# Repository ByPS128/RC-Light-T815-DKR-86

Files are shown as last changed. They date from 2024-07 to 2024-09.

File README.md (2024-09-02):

# RC-Light Controller for T815-DKR-86

## Introduction

RC-Light Controller is a sophisticated system for controlling the lighting of RC models, specifically designed for the 1:12 scale Tatra 815 1986 DAKAR model. This project combines hardware and software solutions to create a realistic and fully functional lighting system for RC models.

## Prerequisites
The control system assumes the use of an RC pistol transmitter with a steering wheel and at least 3 channels.
1. Channel for steering
2. Channel for throttle/brake
3. Channel of button type or a lever with two states (e.g., start/stop, on/off)

For development purposes, I used an inexpensive RC transmitter: TURBO 2.4GHz 91803G-VT 3CH RC Transmitter.

## Outline

1. [Feature Overview](#feature-overview)
2. [System Architecture](#system-architecture)
3. [Main Components](#main-components)
4. [Configuration and Customization](#configuration-and-customization)
5. [Optimization and Efficiency](#optimization-and-efficiency)
6. [Hardware Connection](#hardware-connection)
7. [Installation and Usage](#installation-and-usage)
8. [Project Structure and File Description](#project-structure-and-file-description)

## Feature Overview

- Multiple lighting modes including daytime running lights in 3 levels, long-distance lights
- Dynamic brightness control
- Realistic brake and reverse lights
- Calibration of RC channels for precise control
- Signal loss detection and indication
- Programmable flashing sequences for various system states
- Powered by the model's battery pack, with the option to connect to an independent power source

- Turn signals - this feature is not implemented because I don't need turn signals for the Dakar model. However, it's not difficult to program them. With the architecture I've designed, it's straightforward. If you're reading this and want turn signals but Arduino or C++ isn't your forte, write to me and I'll program it for you.

## System Architecture

The system is built on the Arduino platform and uses an object-oriented approach for a modular and extensible design. Key classes include:

- `MainApp`: Central control class coordinating all components
- `LightsController`: Manages various lighting modes
- `RCChannel`: Processes input signals from the RC receiver
- `CalibrationManager`: Ensures accurate calibration of RC channels
- `LedBlinker`: Provides a flexible interface for programmable LED sequences

## Main Classes

### MainApp

This class serves as the main entry point of the application. It initializes all other components, processes button inputs, and coordinates the overall system behavior.

### LightsController

Manages various lighting modes and controls individual LEDs. Supports smooth transitions between modes and responds to braking and reversing.

### RCChannel

Processes input PWM signals from the RC receiver, provides calibrated values for precise control.

### CalibrationManager

Allows calibration of RC channels for optimal performance. Stores calibration data in EEPROM for permanent retention.

### LedBlinker

A flexible system for creating complex flashing sequences, used to indicate various system states.

## Configuration and Customization

The system can be easily customized by modifying constants in the `AppConstants.h` file. Key configurable parameters include:

- Pin mapping for various functions
- Timing and threshold values for button detection
- Calibration constants for RC signals

To customize lighting behavior, the `LightsController` class can be modified, especially the `LIGHT_MATRIX` which defines various lighting modes.

## Optimization and Efficiency

The project uses several techniques to optimize memory usage and performance:

- Use of `PROGMEM` for storing constants in flash memory
- Efficient use of EEPROM for storing calibration data
- Optimized timing in the main loop to reduce power consumption
- Modular design allowing easy disabling of unused features

## Hardware Connection

The project includes a wiring diagram created in KiCad, providing a detailed view of the system's hardware configuration. The diagram includes the connection of Arduino Nano, RC receiver, LEDs, and other components.

I used the following key components to achieve the goal:

- Arduino Nano - main control unit
- Isolation module with optocoupler - detects motor rotation direction, necessary for movement direction detection
- PWM MOSFET module - creates PWM modulated signal on a separate circuit
- Step-down converter to 5V - powers Arduino and other peripherals
- LEDs .. describe types and properties
- Resistors .. describe quantities and values
- Capacitors .. describe quantities and values
- Transistors .. describe quantities and values
- Other components .. describe quantities and values

## Installation and Usage

1. Upload the code to Arduino Nano
2. Connect the hardware according to the provided diagram
3. Perform RC channel calibration using the built-in calibration mode
4. The system is ready for use - control the lighting using the RC transmitter

For detailed installation and usage instructions, see [documentation](./docs/USAGE.md).

---

This project represents a comprehensive and professional solution for controlling RC model lighting. Thanks to its modular design, efficient memory management, and flexible configuration, the RC-Light Controller is an ideal platform for modelers seeking realistic lighting for their RC models.

## Project Structure and File Description

### RC-Light-T815-DKR-86.ino
The main Arduino project file. Contains `setup()` and `loop()` functions that initialize and control the entire application. Creates an instance of `MainApp` and calls its methods for initialization and updating.

### AppConstants.h
File containing important constants used throughout the application. Defines pin mapping, EEPROM addresses, limits for RC signal validation, and other configuration values. Centralizing these constants facilitates maintenance and customization of the application.

### MainApp.h and MainApp.cpp
Defines the `MainApp` class, which serves as the central control unit for the entire application. Coordinates all other components, processes button inputs, and controls overall system behavior. Implements interfaces for processing button events and LED blinkers.

### RCChannel.h and RCChannel.cpp
The `RCChannel` class represents one channel of the RC receiver. Processes input PWM signals, performs calibration, and provides methods for obtaining current channel values. It is crucial for precise model control.

### CalibrationManager.h and CalibrationManager.cpp
`CalibrationManager` manages the RC channel calibration process. Allows saving and loading calibration data from EEPROM, ensuring that calibration is preserved even after power off.

### LightsController.h and LightsController.cpp
`LightsController` controls various lighting modes of the model. Manages switching between modes, controls individual LEDs, and responds to vehicle state (braking, reversing). Implements logic for various light configurations.

### ButtonBase.h and ButtonBase.cpp
The base class `ButtonBase` provides general functionality for processing button events. Implements detection of various press types (short, long, double) and a system for registering and notifying event subscribers.

### DigitalPullUpButton.h and DigitalPullUpButton.cpp
`DigitalPullUpButton` is a specialized class for working with digital buttons using Arduino's internal pull-up resistors. Inherits from `ButtonBase` and implements specific logic for detecting button presses.

### RcPwmButton.h and RcPwmButton.cpp
`RcPwmButton` is a class derived from `ButtonBase` that interprets PWM signal from the RC receiver as a button state. Allows using an RC channel as a virtual button.

### LedBlinker.h and LedBlinker.cpp
The `LedBlinker` class provides a flexible system for creating various LED blinking sequences. It is used to indicate various system states, such as calibration or signal loss.

### RCSteeringHandler.h and RCSteeringHandler.cpp
`RCSteeringHandler` processes input signals for steering wheel tracking. Implements logic for mapping input values to output actions, including LED brightness setting.

### RCThrottleHandler.h and RCThrottleHandler.cpp
`RCThrottleHandler` processes input signals for tracking the position of the throttle/brake lever. Detects states such as braking and provides this data to other components.

### SignalValidator.h and SignalValidator.cpp
The `SignalValidator` class checks the validity of RC signals. Verifies signal presence and pulse width validity for all RC channels, ensuring control reliability.

### NoiseFilter.h and NoiseFilter.cpp
`NoiseFilter` implements an algorithm for filtering noise in digital signals. Helps eliminate false triggers caused by electrical interference.

### cli.bat
A batch file for Windows that facilitates project compilation using Arduino CLI. Installs necessary libraries and runs compilation for Arduino Nano including cache clearing.

Each of these files plays an important role in the overall architecture of the project, contributing to its modularity, extensibility, and easy maintenance. Together, they create a robust system for controlling RC model lighting with advanced features such as calibration, signal loss detection, and flexible programming of light sequences.

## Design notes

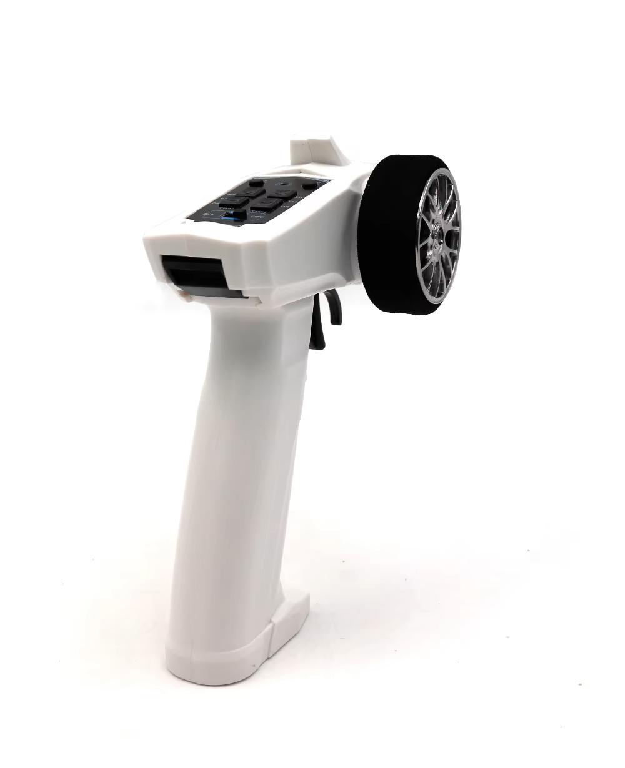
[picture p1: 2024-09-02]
Media/TURBO-91803G-VT-3CH.png

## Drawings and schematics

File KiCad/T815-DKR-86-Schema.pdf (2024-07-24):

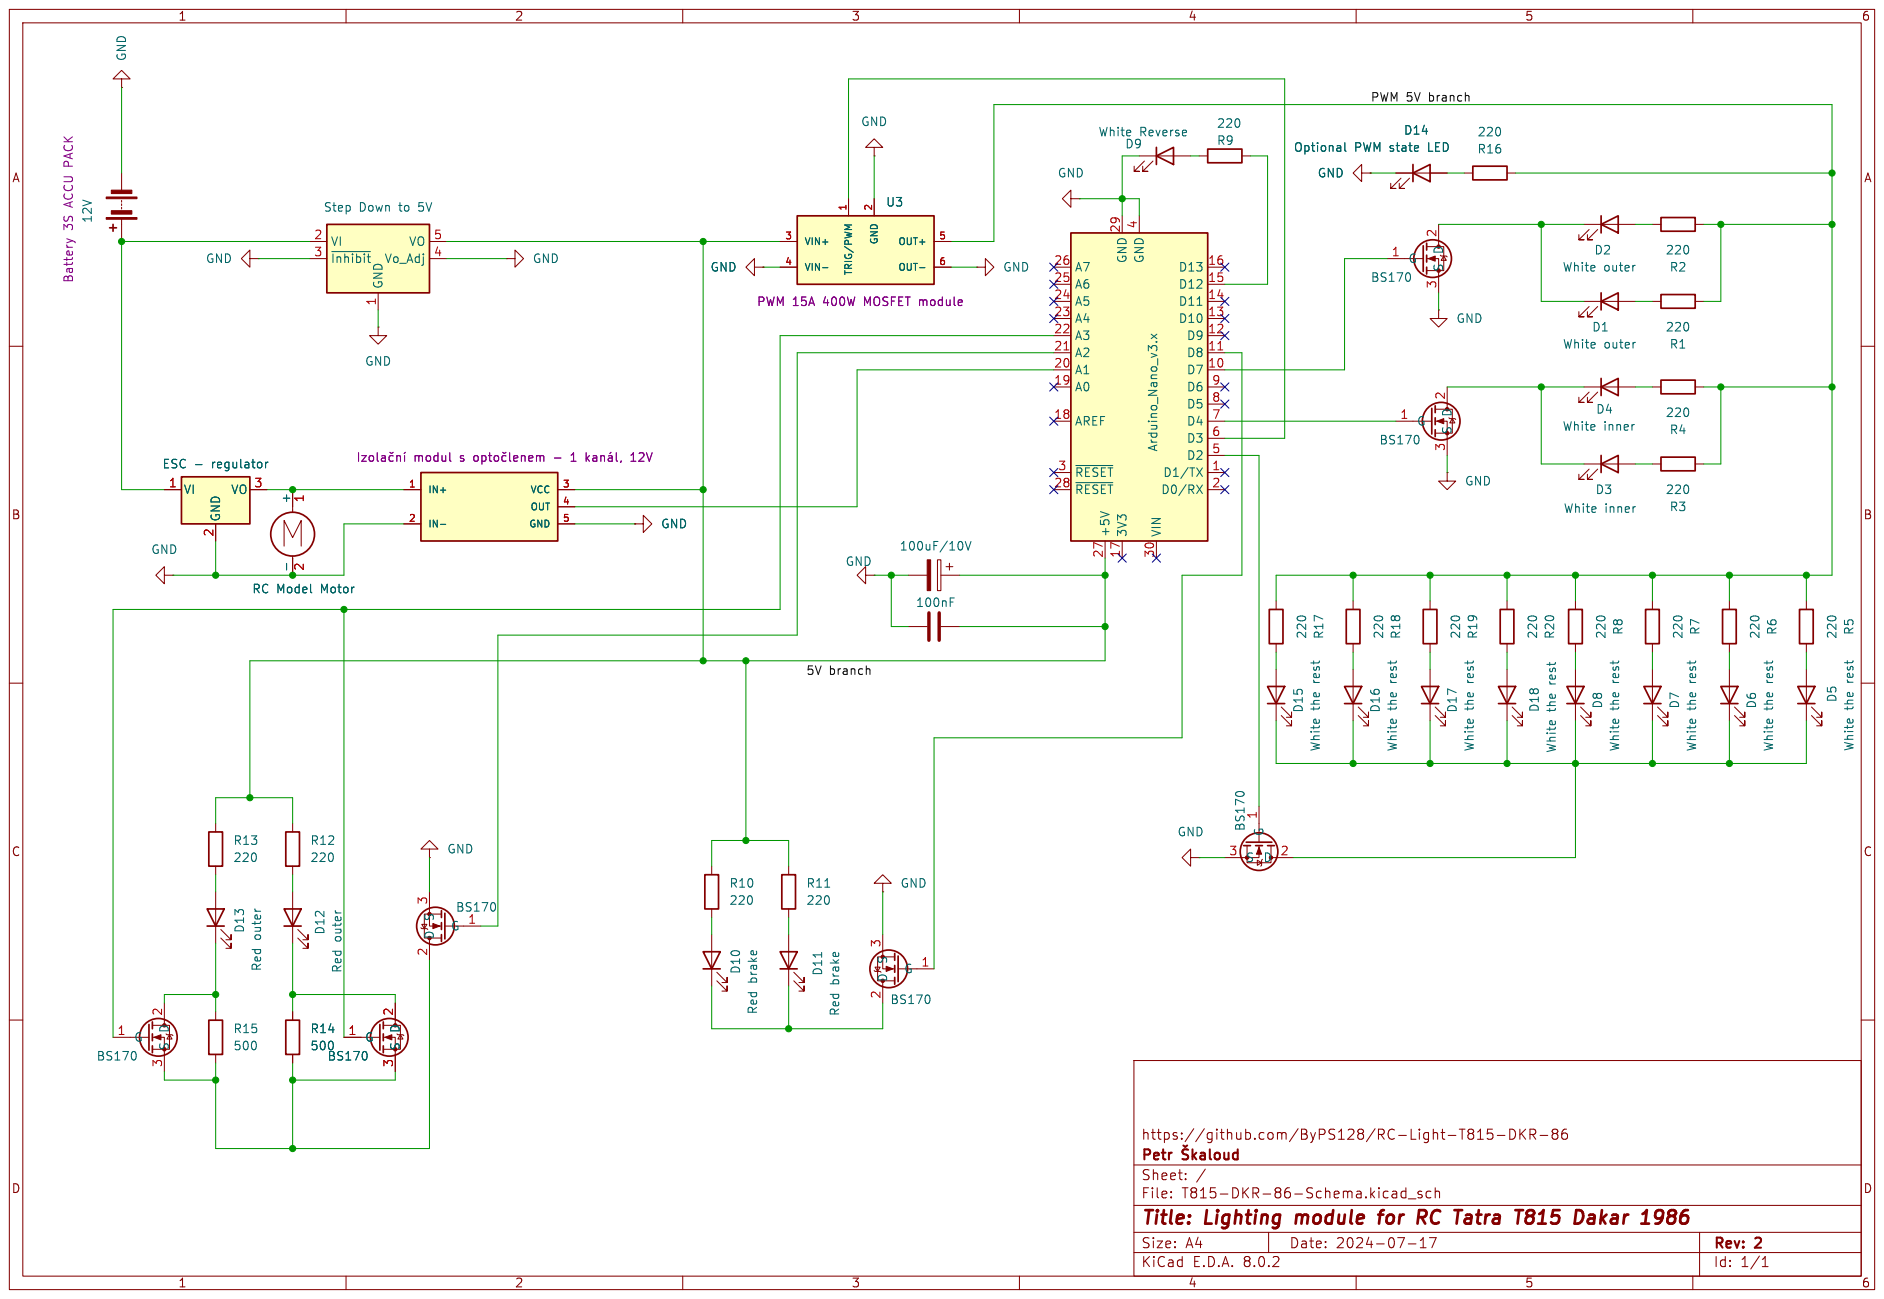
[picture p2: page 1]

2 VO 3 ESC - regulator GND GND

2 VIN+ 3 VIN- 4 OUT- 6 OUT+ 5 U3 PWM 15A 400W MOSFET module D14 Optional PWM state LED GND GND GND D11 Red brake G

U3 PWM 15A 400W MOSFET module TRIG/PWM

1 VI 2 ~{Inhibit} 3 Vo_Adj 4 VO 5 Step Down to 5V GND GND

2 VIN+ 3 VIN- 4 OUT- 6 OUT+ 5 BS170G

3BS170 GND D7 White the rest TRIG/PWM

-2 RC Model Motor GND GND D8 White the rest R3 D3 220 White inner D4 White inner R4

https://github.com/ByPS128/RC-Light-T815-DKR-86
File: T815-DKR-86-Schema.kicad_sch Sheet: / Petr þÿ`kaloud

Id: 1/1 Title: Lighting module for RC Tatra T815 Dakar 1986

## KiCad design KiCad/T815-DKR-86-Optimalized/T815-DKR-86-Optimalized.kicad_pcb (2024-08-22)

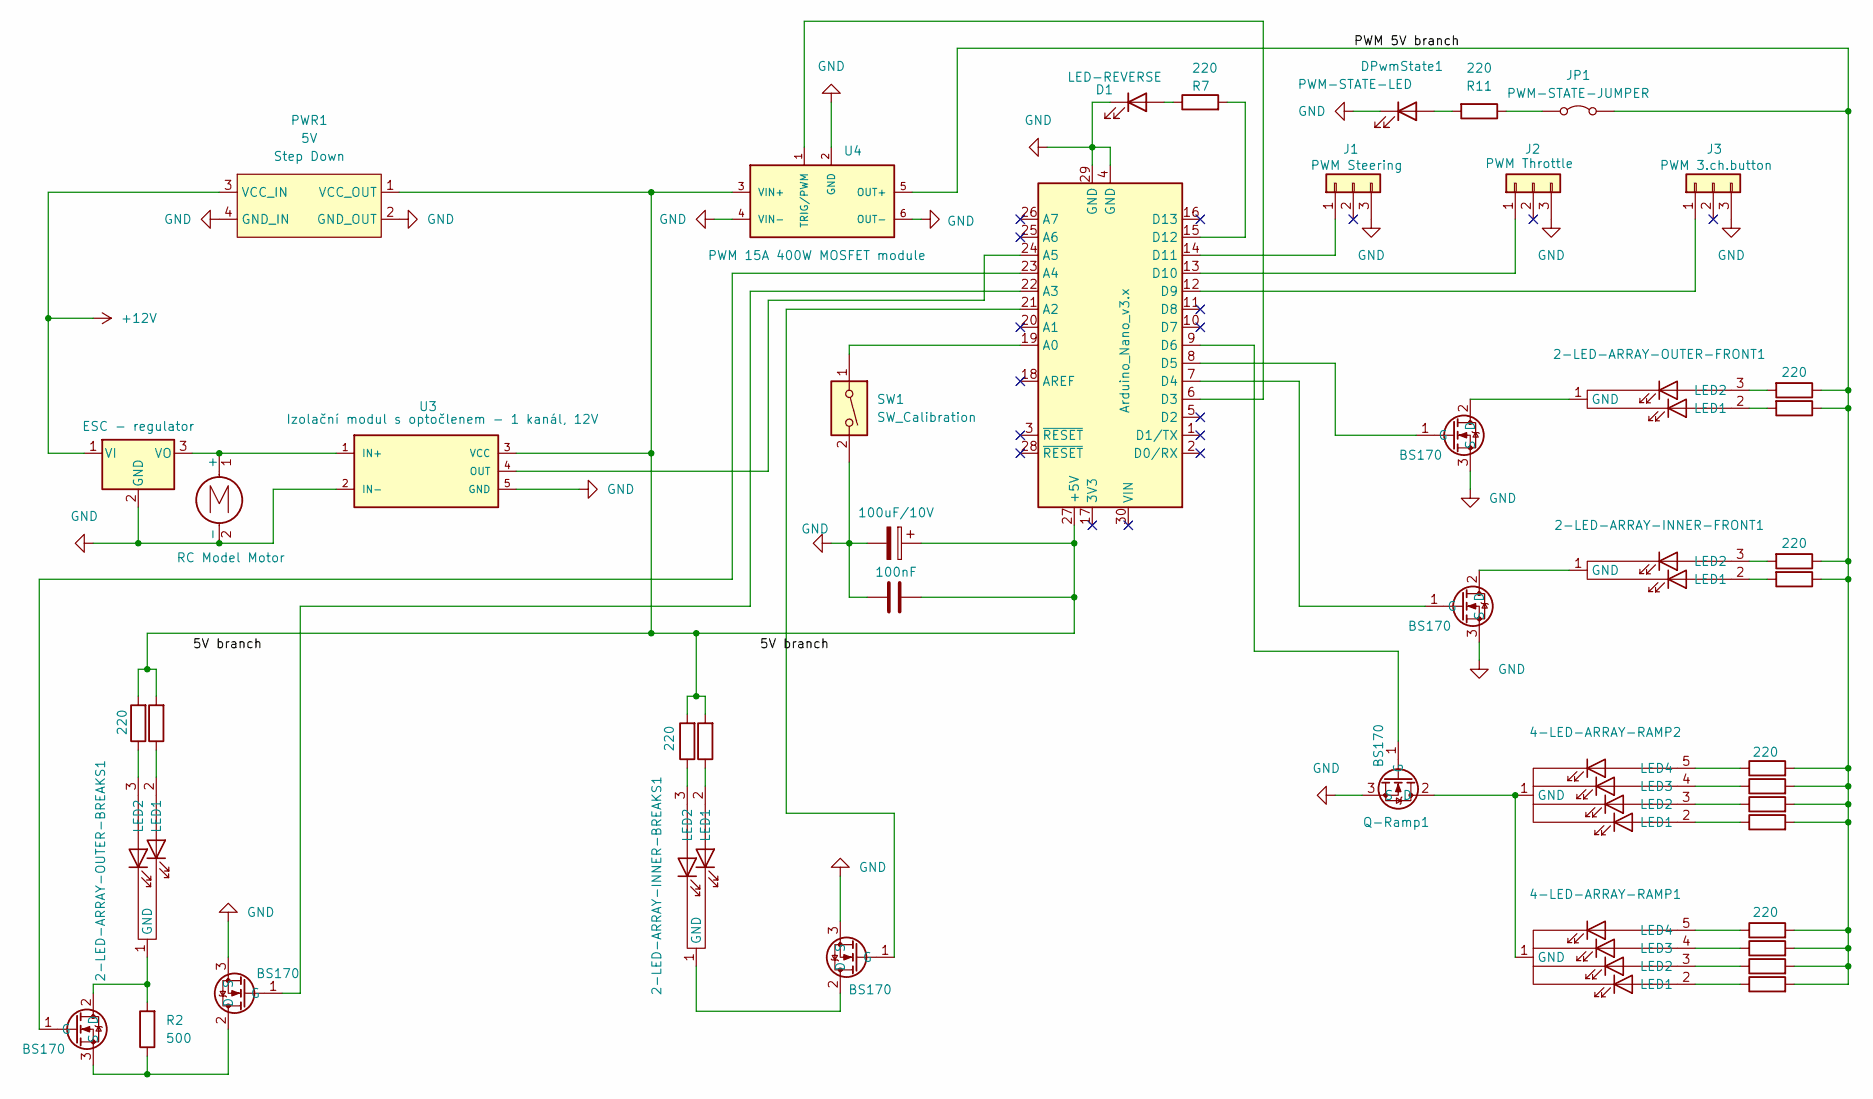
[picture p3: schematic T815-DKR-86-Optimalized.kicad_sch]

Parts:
2-LED-ARRAY-INNER-BREAKS1, 2-LED-ARRAY-INNER-FRONT1, 2-LED-ARRAY-OUTER-BREAKS1, 2-LED-ARRAY-OUTER-FRONT1: JST_XH_B3B-XH-A_1x03_P2.50mm_Vertical
4-LED-ARRAY-RAMP1, 4-LED-ARRAY-RAMP2: JST_XH_B5B-XH-A_1x05_P2.50mm_Vertical
A1: Arduino_Nano_v3.x; Arduino_Nano
C1: 100uF/10V; CP_Radial_D6.3mm_P2.50mm
C2: 100nF; CP_Radial_Tantal_D4.5mm_P2.50mm
D1: LED-REVERSE; JST_XH_B2B-XH-A_1x02_P2.50mm_Vertical
DPwmState1: PWM-STATE-LED; LED_D2.0mm_W4.8mm_H2.5mm_FlatTop
J1: PWM Steering; PinHeader_1x03_P2.54mm_Vertical
J2: PWM Throttle; PinHeader_1x03_P2.54mm_Vertical
J3: PWM 3.ch.button; PinHeader_1x03_P2.54mm_Vertical
JP1: PWM-STATE-JUMPER
M1: RC Model Motor; SolderWire-0.15sqmm_1x02_P4mm_D0.5mm_OD1.5mm
PWR1: 5V; SolderWire-0.15sqmm_1x02_P4mm_D0.5mm_OD1.5mm
Q1, Q3, Q4: BS170; BS170-TO-92L_Inline_Wide
Q6, Q7: BS170; TO-92L_Inline_Wide
Q-Ramp1: BS170; BS170-TO-92L_Inline_Wide
R1, R3, R5, R6, R7, R8, R9, R10, R11, R12, R13, R14, R15, R16, R17, R18, R19, R20: 220; R_Axial_DIN0204_L3.6mm_D1.6mm_P2.54mm_Vertical
R2: 500; R_Axial_DIN0204_L3.6mm_D1.6mm_P2.54mm_Vertical
SW1: SW_Calibration; LED_D2.0mm_W4.8mm_H2.5mm_FlatTop
U1: ESC - regulator
U3: Optocoupler_Module; Izolační modul s optočlenem
U4: PWM_MOSFET_Module; PWM-Module

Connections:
/PWM 5V branch: JP1.2 (B), R8.2, R9.2, R10.2, R12.2, R13.2, R14.2, R15.1, R16.1, R17.1, R18.1, R19.2, R20.2, U4.5 (OUT+)
GND: A1.4 (GND), A1.29 (GND), C1.2, C2.1, D1.1 (K), DPwmState1.1 (K), J1.3, J2.3, J3.3, M1.2 (-), PWR1.2 (GND_OUT), PWR1.4 (GND_IN), Q3.3 (S), Q4.3 (S), Q6.3 (S), Q7.3 (S), Q-Ramp1.3 (S), SW1.2, U1.2 (GND), U3.2 (IN-), U3.5 (GND), U4.2 (GND), U4.4 (VIN-), U4.6 (OUT-)
unnamed: 2-LED-ARRAY-INNER-BREAKS1.1 (GND), Q4.2 (D)
unnamed: 2-LED-ARRAY-INNER-BREAKS1.2 (LED1), R6.1
unnamed: 2-LED-ARRAY-INNER-BREAKS1.3 (LED2), R5.1
unnamed: 2-LED-ARRAY-INNER-FRONT1.1 (GND), Q7.2 (D)
unnamed: 2-LED-ARRAY-INNER-FRONT1.2 (LED1), R18.2
unnamed: 2-LED-ARRAY-INNER-FRONT1.3 (LED2), R17.2
unnamed: 2-LED-ARRAY-OUTER-BREAKS1.1 (GND), Q1.2 (D), R2.2
unnamed: 2-LED-ARRAY-OUTER-BREAKS1.2 (LED1), R3.1
unnamed: 2-LED-ARRAY-OUTER-BREAKS1.3 (LED2), R1.1
unnamed: 2-LED-ARRAY-OUTER-FRONT1.1 (GND), Q6.2 (D)
unnamed: 2-LED-ARRAY-OUTER-FRONT1.2 (LED1), R16.2
unnamed: 2-LED-ARRAY-OUTER-FRONT1.3 (LED2), R15.2
unnamed: 4-LED-ARRAY-RAMP1.1 (GND), 4-LED-ARRAY-RAMP2.1 (GND), Q-Ramp1.2 (D)
unnamed: 4-LED-ARRAY-RAMP1.2 (LED1), R13.1
unnamed: 4-LED-ARRAY-RAMP1.3 (LED2), R14.1
unnamed: 4-LED-ARRAY-RAMP1.4 (LED3), R19.1
unnamed: 4-LED-ARRAY-RAMP1.5 (LED4), R20.1
unnamed: 4-LED-ARRAY-RAMP2.2 (LED1), R8.1
unnamed: 4-LED-ARRAY-RAMP2.3 (LED2), R9.1
unnamed: 4-LED-ARRAY-RAMP2.4 (LED3), R10.1
unnamed: 4-LED-ARRAY-RAMP2.5 (LED4), R12.1
unnamed: A1.27 (+5V), C1.1, C2.2, PWR1.1 (VCC_OUT), R1.2, R3.2, R5.2, R6.2, U3.3 (VCC), U4.3 (VIN+)
unnamed: A1.19 (A0), SW1.1
unnamed: A1.21 (A2), Q4.1 (G)
unnamed: A1.22 (A3), Q3.1 (G)
unnamed: A1.23 (A4), Q1.1 (G)
unnamed: A1.24 (A5), U3.4 (OUT)
unnamed: A1.6 (D3), U4.1 (TRIG/PWM)
unnamed: A1.7 (D4), Q7.1 (G)
unnamed: A1.8 (D5), Q6.1 (G)
unnamed: A1.9 (D6), Q-Ramp1.1 (G)
unnamed: A1.12 (D9), J3.1
unnamed: A1.13 (D10), J2.1
unnamed: A1.14 (D11), J1.1
unnamed: A1.15 (D12), R7.2
unnamed: D1.2 (A), R7.1
unnamed: DPwmState1.2 (A), R11.2
unnamed: JP1.1 (A), R11.1
unnamed: M1.1 (+), U1.3 (VO), U3.1 (IN+)
unnamed: Q1.3 (S), Q3.2 (D), R2.1
unnamed: PWR1.3 (VCC_IN), U1.1 (VI)

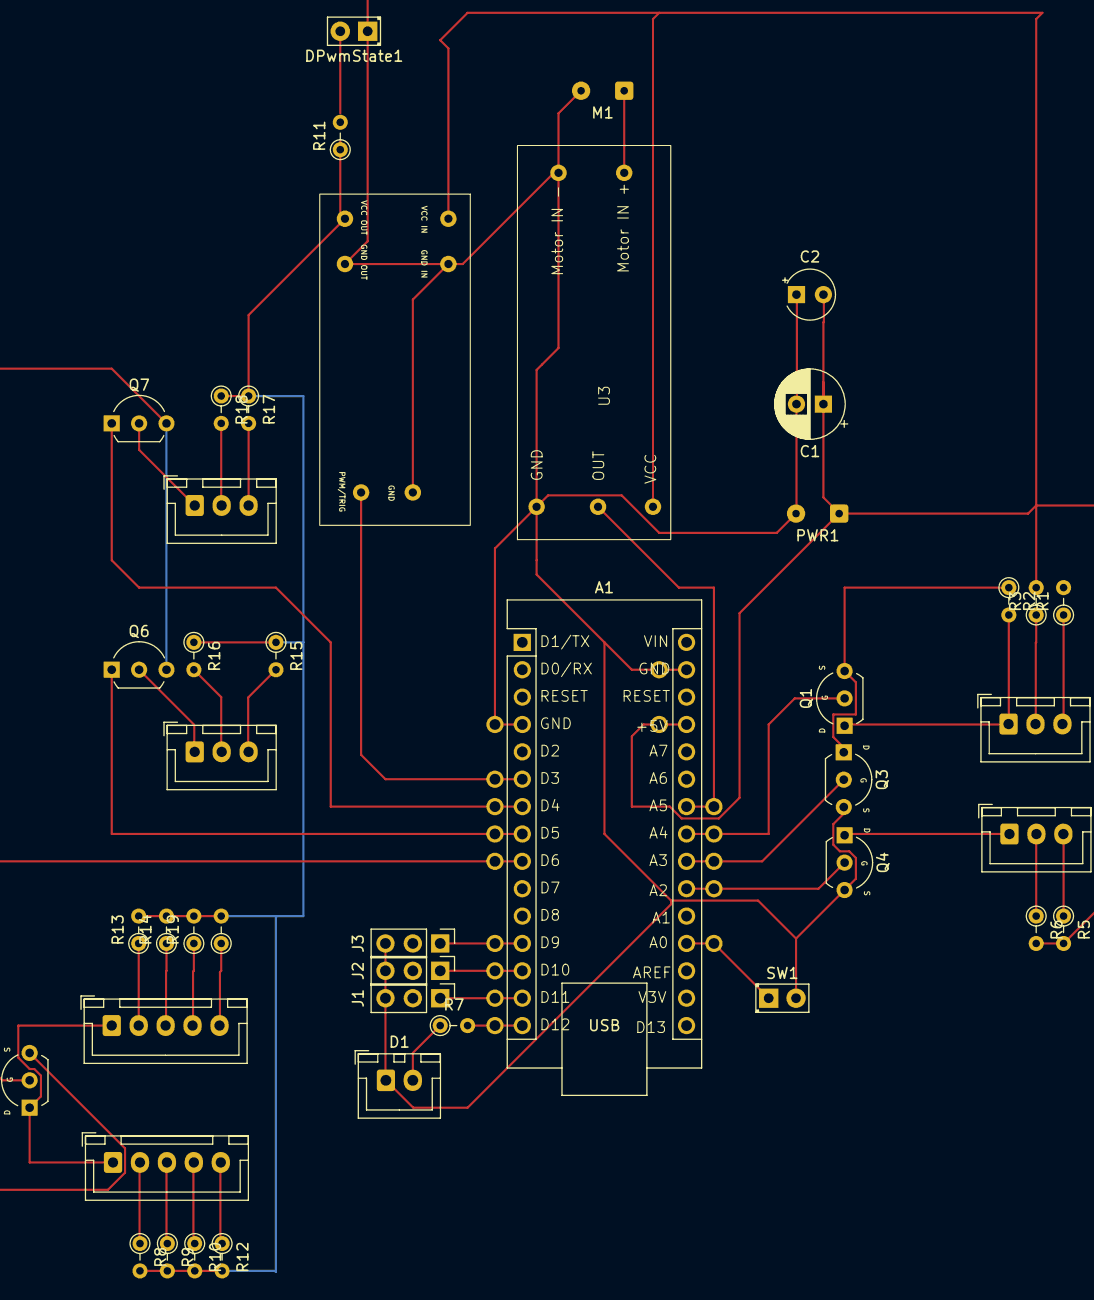
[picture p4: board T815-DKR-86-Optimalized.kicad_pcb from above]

Board: 2 copper layers, 44 parts (0 on the bottom side), 41 nets.

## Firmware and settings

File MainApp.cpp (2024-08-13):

#include <Arduino.h>
#include <EEPROM.h>
#include "MainApp.h"
#include "AppConstants.h"

MainApp::MainApp()
  : rcButton(AppConstants::BUTTON_CONTROL), calibrationButton(AppConstants::BUTTON_CALIBRATION), currentMode(ProgrammingModes::None), ledBrightness(0) {
}

void MainApp::init() {
  setupPins();

  channels[0] = new RCChannel(AppConstants::PIN_PWM_STEERING);
  channels[1] = new RCChannel(AppConstants::PIN_PWM_THROTTLE);
  channels[2] = new RCChannel(AppConstants::PIN_PWM_BUTTON);

  signalValidator = new SignalValidator(channels);
  calibrationManager = new CalibrationManager(channels);
  //calibrationManager->clearEEPROM();
  calibrationManager->init();

  calibrationButton.init(AppConstants::PIN_CALIBRATION_BUTTON);
  calibrationButton.registerSubscriber(this);

  rcButton.init(channels[2]);
  rcButton.registerSubscriber(this);

  throttleHandler.init(channels[1], AppConstants::PIN_DIGI_MOTOR_BACKWARD);
  ledBlinker.init(AppConstants::PIN_PWM_LIGHT_BRIGHTNESS_LED, AppConstants::PIN_SIGNAL_LED);
  ledBlinker.registerSubscriber(this);

  steeringHandler.init(channels[0], AppConstants::PIN_PWM_LIGHT_BRIGHTNESS_LED, AppConstants::PIN_SIGNAL_LED);
  readLedBrightnessValueFromEprom();

  // setup of No signal animator
  noSignalBlinker.init(AppConstants::PIN_PWM_LIGHT_BRIGHTNESS_LED, AppConstants::PIN_DIGI_LIGHT_MODE_1_LED, 
                       AppConstants::PIN_DIGI_LIGHT_MODE_2_LED, AppConstants::PIN_DIGI_LIGHT_MODE_3_LED,
                       AppConstants::PIN_DIGI_OUTER_BRAKE_LED, AppConstants::PIN_DIGI_OUTER_BRAKE_MODE,
                       AppConstants::PIN_DIGI_INNER_BRAKE_LED, AppConstants::PIN_DIGI_REVERSE_LED);
  noSignalBlinker.registerSubscriber(this);
  setupNoSignal();

  // setup of Not calibrated animator
  notCalibratedBlinker.init(AppConstants::PIN_PWM_LIGHT_BRIGHTNESS_LED, AppConstants::PIN_DIGI_LIGHT_MODE_1_LED, 
                            AppConstants::PIN_DIGI_LIGHT_MODE_2_LED, AppConstants::PIN_DIGI_LIGHT_MODE_3_LED,
                            AppConstants::PIN_DIGI_OUTER_BRAKE_LED, AppConstants::PIN_DIGI_OUTER_BRAKE_MODE,
                            AppConstants::PIN_DIGI_INNER_BRAKE_LED, AppConstants::PIN_DIGI_REVERSE_LED);
  notCalibratedBlinker.registerSubscriber(this);
  setupNotCalibrated();

  // Setup and set light controller to NO lights are shining.
  lightsController.init(LightsController::MODE_NONE,
                        ledBrightness, AppConstants::PIN_PWM_LIGHT_BRIGHTNESS_LED,
                        AppConstants::PIN_DIGI_LIGHT_MODE_1_LED, AppConstants::PIN_DIGI_LIGHT_MODE_2_LED, AppConstants::PIN_DIGI_LIGHT_MODE_3_LED,
                        AppConstants::PIN_DIGI_OUTER_BRAKE_LED, AppConstants::PIN_DIGI_OUTER_BRAKE_MODE,
                        AppConstants::PIN_DIGI_INNER_BRAKE_LED, AppConstants::PIN_DIGI_REVERSE_LED);

  if (!calibrationManager->isCalibrated()) {
    Serial.println(F("RC system not calibrated. Press calibration button to start calibration."));
    notCalibratedBlinker.start();
    return;
  }

  updateRcChannels();
  if (!signalValidator->isSignalValid()) {
    Serial.println(F("No signal, turn on RC transmiter and receiver."));
    noSignalBlinker.start();
    return;
  }

  // When all valid, play led animation.
  blinkApplicationReady();
}

void MainApp::update() {
  // If the LED animation is running, I don't perform any logic,
  // because I need to let finish the current animation.
  if (ledBlinker.updateBlinking()) {
    // LED Animation is in progress.
    Serial.print("*");
    // Small pause to reduce CPU load
    delay(AppConstants::LOOP_DELAY);
    return;
  }

  // Channels have to be read first of all.
  updateRcChannels();
  //describeRcChannel(2, true);

  // Calibration workflow
  if (notCalibratedBlinker.getIsBlinking()) {
    notCalibratedBlinker.updateBlinking();
    if (calibrationManager->isCalibrated()) {
      notCalibratedBlinker.stop();
    }

    // give chance to calibrate
    calibrationButton.update();

    delay(AppConstants::LOOP_DELAY);
    return;
  }
  if (!calibrationManager->isCalibrated()) {
    if (!notCalibratedBlinker.getIsBlinking()) {
      notCalibratedBlinker.start();
    } else {
      notCalibratedBlinker.updateBlinking();
    }

    delay(AppConstants::LOOP_DELAY);
    return;
  }

  // Sighnal workflow
  if (!signalValidator->isSignalValid()) {
    // Reakce na neplatný signál (např. bezpečnostní opatření)
    Serial.print("x");
    noSignalBlinker.updateBlinking();

    delay(AppConstants::LOOP_DELAY);
    return;
  }

  // When signal is restored and blinker is blinking,
  // I must stop blinking and RESTORE light mode.
  if (noSignalBlinker.getIsBlinking()) {
    noSignalBlinker.stop();
    lightsController.setLightsPinsByCurrentMode();
    Serial.println(F("Signal restored"));
  }

  calibrationButton.update();

  if (calibrationManager->isInCalibrationMode()) {
    delay(AppConstants::LOOP_DELAY);
    return;
  }

  rcButton.update();
  throttleHandler.update();

  bool stateChanged = lightsController.setReverse(throttleHandler.isReverse());
  stateChanged |= lightsController.setBreaking(throttleHandler.isBreaking());
  if (stateChanged) {
    lightsController.setLightsPinsByCurrentMode();
  }

  // I will perform the actions depending on the programming mode.
  switch (currentMode) {
    case ProgrammingModes::None:
      // I'm not in programming mode
      break;
    case ProgrammingModes::BrightnessAdjustment:
      // I'm in LED brightness adjustment mode
      steeringHandler.updateBrightnessAdjustment();
      break;
  }

  delay(AppConstants::LOOP_DELAY);  // Small pause to reduce CPU load
}

void MainApp::updateRcChannels() {
  for (int i = 0; i < AppConstants::CHANNEL_COUNT; i++) {
    channels[i]->update();
  }
  calibrationManager->update();
}

void MainApp::onButtonClick(int buttonId, ButtonClickType clickKind) {
  Serial.print(F("OnClick(id:"));
  Serial.print(buttonId);
  Serial.print(F(") -> "));
  Serial.println(buttonClickTypeToString(clickKind));

  if (buttonId == AppConstants::BUTTON_CONTROL) {
    onRcPwmButtonClick(clickKind);
    return;
  }

  if (buttonId == AppConstants::BUTTON_CALIBRATION) {
    onCalibrationButtonClick(clickKind);
    return;
  }
}

void MainApp::onCalibrationButtonClick(ButtonClickType clickKind) {
  if (clickKind == ButtonClickType::LongPress && !calibrationManager->isInCalibrationMode()) {
    calibrationManager->startCalibration();
    return;
  }

  if (clickKind == ButtonClickType::DoubleClick && calibrationManager->isInCalibrationMode()) {
    calibrationManager->terminateCalibrationMode();
    return;
  }

  if (clickKind == ButtonClickType::Click && calibrationManager->isInCalibrationMode()) {
    calibrationManager->turnCalibrationMode();
    return;
  }
}

void MainApp::onRcPwmButtonClick(ButtonClickType clickKind) {
  // Standard single click when no programming mode is in progress.
  if (clickKind == ButtonClickType::Click && currentMode == ProgrammingModes::None) {
    lightsController.turnToNextLightMode();
    return;
  }

  // Standard double click when no programming mode is in progress.
  if (clickKind == ButtonClickType::DoubleClick && currentMode == ProgrammingModes::None) {
    lightsController.turnMaximumLights();
    return;
  }

  // Single click in brightness adjustment programming mode,
  // it will end the mdoe and store calibrated values.
  // It also turn mode to standart mode -> none.
  if (clickKind == ButtonClickType::Click && currentMode == ProgrammingModes::BrightnessAdjustment) {
    currentMode = ProgrammingModes::None;
    writeLedBrightnessValueToEprom();
    lightsController.setLedBirigthness(ledBrightness);
    blinkWriteOK();
    return;
  }

  if (clickKind == ButtonClickType::LongPress && currentMode == ProgrammingModes::None) {
    currentMode = ProgrammingModes::BrightnessAdjustment;
    blinkStartBrightnessAdjustment();
    return;
  }

  if (clickKind == ButtonClickType::ClickAndLongPress && currentMode == ProgrammingModes::None) {
    // not used
    return;
  }
}

void MainApp::onLedBlinkerAnimationStop(LedBlinker* instance) {
  (void)instance;
  lightsController.setLightsPinsByCurrentMode();
}

// private methods follows

void MainApp::setupPins() {
  pinMode(AppConstants::PIN_PWM_BUTTON, INPUT);
  pinMode(AppConstants::PIN_PWM_STEERING, INPUT);
  pinMode(AppConstants::PIN_PWM_THROTTLE, INPUT);
  pinMode(AppConstants::PIN_CALIBRATION_BUTTON, INPUT);
  pinMode(AppConstants::PIN_DIGI_MOTOR_BACKWARD, INPUT);

  pinMode(AppConstants::PIN_PWM_LIGHT_BRIGHTNESS_LED, OUTPUT);
  pinMode(AppConstants::PIN_DIGI_LIGHT_MODE_1_LED, OUTPUT);
  pinMode(AppConstants::PIN_DIGI_LIGHT_MODE_2_LED, OUTPUT);
  pinMode(AppConstants::PIN_DIGI_LIGHT_MODE_3_LED, OUTPUT);
  pinMode(AppConstants::PIN_DIGI_OUTER_BRAKE_LED, OUTPUT);
  pinMode(AppConstants::PIN_DIGI_OUTER_BRAKE_MODE, OUTPUT);
  pinMode(AppConstants::PIN_DIGI_INNER_BRAKE_LED, OUTPUT);
  pinMode(AppConstants::PIN_DIGI_REVERSE_LED, OUTPUT);
}

void MainApp::readLedBrightnessValueFromEprom() {
  ledBrightness = EEPROM.read(AppConstants::LED_BRIGHTNESS_VALUE_ADDRESS);

  steeringHandler.setLedBrightness(ledBrightness);

  Serial.print(F("EPROM read brightness: "));
  Serial.println(ledBrightness);
}

void MainApp::writeLedBrightnessValueToEprom() {
  if (currentMode == ProgrammingModes::BrightnessAdjustment) {
    ledBrightness = steeringHandler.getLedBrightness();
  }

  EEPROM.write(AppConstants::LED_BRIGHTNESS_VALUE_ADDRESS, ledBrightness);

  Serial.print(F("EPROM write brightness: "));
  Serial.println(ledBrightness);
}

void MainApp::blinkApplicationReady() {
  Serial.println(F("Application ready"));
  ledBlinker.setupBlinkingSequence(5, ledBrightness < 64 ? 64 : ledBrightness, 50, LOW, 50, LOW, 500);
  ledBlinker.start();
}

void MainApp::blinkStartCalibrating() {
  Serial.println(F("Start calibrating"));
  ledBlinker.setupBlinkingSequence(3, ledBrightness < 64 ? 64 : ledBrightness, 100, LOW, 250, LOW, 500);
  ledBlinker.start();
}

void MainApp::blinkStartBrightnessAdjustment() {
  Serial.println(F("Start adjusting brightness"));
  ledBlinker.setupBlinkingSequence(2, ledBrightness < 64 ? 64 : ledBrightness, 100, LOW, 250, LOW, 500);
  ledBlinker.start();
}

void MainApp::blinkWriteOK() {
  Serial.println(F("programming ended"));
  ledBlinker.setupBlinkingSequence(2, ledBrightness < 64 ? 64 : ledBrightness, 100, LOW, 250, LOW, 500);
  ledBlinker.start();
}

void MainApp::setupNotCalibrated() {
  // Sequence definition for SOS
  LedBlinker::BlinkStep sequence[] = {
    { 100, ledBrightness < 64 ? 64 : ledBrightness },
    { 50, LOW },
    { 100, ledBrightness < 64 ? 64 : ledBrightness },
    { 300, LOW },
  };
  unsigned int sequenceLength = sizeof(sequence) / sizeof(LedBlinker::BlinkStep);

  notCalibratedBlinker.enableInfiniteLoop();
  notCalibratedBlinker.setupBlinkingSequence(sequence, sequenceLength);
}

void MainApp::setupNoSignal() {
  noSignalBlinker.enableInfiniteLoop();
  noSignalBlinker.setupBlinkingSequence(2, ledBrightness < 64 ? 64 : ledBrightness, 250, LOW, 250, LOW, 0);
}

const __FlashStringHelper* MainApp::buttonClickTypeToString(ButtonClickType kind) {
  static const char click[] PROGMEM = "Click";
  static const char doubleClick[] PROGMEM = "DoubleClick";
  static const char longPress[] PROGMEM = "LongPress";
  static const char clickAndLongPress[] PROGMEM = "ClickAndLongPress";
  static const char unknown[] PROGMEM = "Unknown";

  switch (kind) {
    case ButtonClickType::Click:
      return reinterpret_cast<const __FlashStringHelper*>(click);
    case ButtonClickType::DoubleClick:
      return reinterpret_cast<const __FlashStringHelper*>(doubleClick);
    case ButtonClickType::LongPress:
      return reinterpret_cast<const __FlashStringHelper*>(longPress);
    case ButtonClickType::ClickAndLongPress:
      return reinterpret_cast<const __FlashStringHelper*>(clickAndLongPress);
    default:
      return reinterpret_cast<const __FlashStringHelper*>(unknown);
  }
}

void MainApp::describeRcChannel(int channelIndex, bool performLineFeed) {
  // Serial.print("Channel ");
  // Serial.print(channelIndex);
  // Serial.print("-");
  // Serial.print(channels[channelIndex]->getNamedPosition());

  // Serial.print("-> min: ");
  // Serial.print(channels[channelIndex]->getMin());
  // Serial.print(", mid: ");
  // Serial.print(channels[channelIndex]->getNeutral());
  // Serial.print(", max: ");
  // Serial.print(channels[channelIndex]->getMax());
  // Serial.print(": ");
  // Serial.print(channels[channelIndex]->getValue());

  // if (performLineFeed) {
  //   Serial.println();
  // }
}

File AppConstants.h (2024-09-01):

#pragma once

#include <Arduino.h>

namespace AppConstants {
  constexpr uint8_t LOOP_DELAY = 10;

  constexpr uint8_t BYTE_MIN = 0;
  constexpr uint8_t BYTE_MAX = 255;

  // BUTTON IDS
  constexpr uint8_t BUTTON_CONTROL = 1;
  constexpr uint8_t BUTTON_CALIBRATION = 2;

  // Assigning Arduino pins to application constants.
  constexpr uint8_t PIN_PWM_STEERING = 9;
  constexpr uint8_t PIN_PWM_THROTTLE = 10;
  constexpr uint8_t PIN_PWM_BUTTON = 11;  // In most 3-channel RC kits, the 3rd channel is in the form of a button.
  constexpr uint8_t PIN_PWM_LIGHT_BRIGHTNESS_LED = 3;
  constexpr uint8_t PIN_DIGI_LIGHT_MODE_1_LED = A3; // outer
  constexpr uint8_t PIN_DIGI_LIGHT_MODE_2_LED = A4; // inner
  constexpr uint8_t PIN_DIGI_LIGHT_MODE_3_LED = A5; // ramp
  constexpr uint8_t PIN_CALIBRATION_BUTTON = 2;
  constexpr uint8_t PIN_DIGI_MOTOR_BACKWARD = A6;
  constexpr uint8_t PIN_DIGI_OUTER_BRAKE_LED = A1;
  constexpr uint8_t PIN_DIGI_OUTER_BRAKE_MODE = A0;
  constexpr uint8_t PIN_DIGI_INNER_BRAKE_LED = A2;
  constexpr uint8_t PIN_DIGI_REVERSE_LED = 12;
  constexpr uint8_t PIN_SIGNAL_LED = PIN_DIGI_LIGHT_MODE_1_LED;

  // Addresses to EPROM for permanent storage of set values of variables.
  constexpr uint16_t LED_BRIGHTNESS_VALUE_ADDRESS = 0x00F0;

  // Constants for Calibration Manager
  const uint16_t EEPROM_MAGIC_ADDRESS = 0x0000;                                  // Začínáme od adresy 128
  const uint16_t EEPROM_MAGIC_NUMBER = 0xABCD;                                   // Unikátní číslo pro identifikaci platných dat
  const uint16_t EEPROM_DATA_START_ADDRESS = EEPROM_MAGIC_ADDRESS + sizeof(int); // Začátek dat hned za magic number
  const uint8_t CHANNEL_COUNT = 3;                                              // Předpokládaný počet kanálů (upravte podle potřeby)

  // Výpočet velikosti dat pro jeden kanál
  const uint16_t CHANNEL_DATA_SIZE = CHANNEL_COUNT * sizeof(int);  // min, max, neutral jsou int

  // Celková velikost dat v EEPROM
  const uint16_t TOTAL_EEPROM_SIZE = EEPROM_DATA_START_ADDRESS + (CHANNEL_COUNT * CHANNEL_DATA_SIZE);

  // Constants for RC signal validation
  const uint16_t MIN_PULSE_WIDTH_US = 900;
  const uint16_t MAX_PULSE_WIDTH_US = 2100;
}

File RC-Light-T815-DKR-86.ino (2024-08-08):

#include <Arduino.h>
#include <EEPROM.h>
#include "MainApp.h"

MainApp mainApp;

void setup() {
  Serial.begin(9600);
  delay(1000);
  
  Serial.print(F("EEPROM size: "));
  Serial.println(EEPROM.length());

  Serial.println(F("Booting"));
  mainApp.init();
}

void loop() {
  Serial.print(F("Free memory: "));
  Serial.println(freeMemory());

  mainApp.update();
}

// Funkce pro zjištění volné paměti
int freeMemory() {
  extern int __heap_start, *__brkval;
  int v;
  return (int) &v - (__brkval == 0 ? (int) &__heap_start : (int) __brkval);
}

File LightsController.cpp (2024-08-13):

#include "LightsController.h"

// Definice statického člena třídy
const uint8_t PROGMEM LightsController::LIGHT_MATRIX[4][3] = {
    { 0, 0, 0 },  // Mode No Lights
    { 1, 0, 0 },  // Mode Outer Day Light Only
    { 1, 1, 0 },  // Mode Outer Day Light Plus Long Light
    { 1, 1, 1 },  // Mode All Lights
};

LightsController::LightsController()
  : pwmFrontLightsPin(0), digitalLight1Pin(0), digitalLight2Pin(0), digitalLight3Pin(0), digitalOuterBrakePin(0), digitalOuterBrakeModePin(0),
    digitalInnerBrakePin(0), digitalReversePin(0), currentLightMode(MODE_NONE), isBreaking(false), isReverse(false),
    isFullLightMode(false), ledBrightness(0) {
}

void LightsController::init(uint8_t lightMode, uint8_t ledBrightness, uint8_t pwmFrontLightsPin,
                            uint8_t digitalLight1Pin, uint8_t digitalLight2Pin, uint8_t digitalLight3Pin,
                            uint8_t digitalOuterBrakePin, uint8_t digitalOuterBrakeModePin,
                            uint8_t digitalInnerBrakePin, uint8_t digitalReversePin) {
  currentLightMode = lightMode;
  this->ledBrightness = ledBrightness;
  this->pwmFrontLightsPin = pwmFrontLightsPin;
  this->digitalLight1Pin = digitalLight1Pin;
  this->digitalLight2Pin = digitalLight2Pin;
  this->digitalLight3Pin = digitalLight3Pin;
  this->digitalOuterBrakeModePin = digitalOuterBrakeModePin;
  this->digitalOuterBrakePin = digitalOuterBrakePin;
  this->digitalInnerBrakePin = digitalInnerBrakePin;
  this->digitalReversePin = digitalReversePin;
  isBreaking = false;
  isReverse = false;
  isFullLightMode = false;
  setLightsPinsByCurrentMode();
}

void LightsController::turnToNextLightMode() {
  currentLightMode = (currentLightMode + 1) % (MODE_MAX + 1);
  setLightsPinsByCurrentMode();
}

byte LightsController::getCurrentLightMode() {
  return currentLightMode;
}

bool LightsController::setBreaking(bool state) {
  bool oldIsBreaking = isBreaking;
  isBreaking = state;

  return isBreaking != oldIsBreaking;
}

bool LightsController::setReverse(bool state) {
  bool oldIsReverse = isReverse;
  isReverse = state;
  return isReverse != oldIsReverse;
}

void LightsController::turnMaximumLights() {
  isFullLightMode = !isFullLightMode;
  setLightsPinsByCurrentMode();
}

void LightsController::setLightsPinsByCurrentMode() {
  bool lightsAreOn = pgm_read_byte(&LIGHT_MATRIX[currentLightMode][0]) == 1;
  // Serial.print(F("is reverse: "));
  // Serial.print(isReverse);
  // Serial.print(F(", is breaking: "));
  // Serial.println(isBreaking);

  // Reverse white light - uses full brightness
  digitalWrite(digitalReversePin, isReverse ? HIGH : LOW);

  // Inner only brake light
  digitalWrite(digitalInnerBrakePin, isBreaking ? HIGH : LOW);  // Turned ON when breaking only.

  // Outer brake light, it is combined brake and day lights (dimmed).
  digitalWrite(digitalOuterBrakePin, lightsAreOn || isBreaking ? HIGH : LOW);  // Turned on when front lights are ON or when breaking.
  digitalWrite(digitalOuterBrakeModePin, isBreaking ? HIGH : LOW);             // If breaking, shine on max, otherwise dimmed.

  if (isFullLightMode) {
    // Set PWM to full brightness of lights circuit
    analogWrite(pwmFrontLightsPin, AppConstants::BYTE_MAX);
    // All front white lights set ON
    digitalWrite(digitalLight1Pin, HIGH);
    digitalWrite(digitalLight2Pin, HIGH);
    digitalWrite(digitalLight3Pin, HIGH);
    return;
  }

  // Set PWM custom brightness of lights circuit
  analogWrite(pwmFrontLightsPin, ledBrightness);
  // Front white lights set ON by mode
  digitalWrite(digitalLight1Pin, pgm_read_byte(&LIGHT_MATRIX[currentLightMode][0]) == 1 ? HIGH : LOW);
  digitalWrite(digitalLight2Pin, pgm_read_byte(&LIGHT_MATRIX[currentLightMode][1]) == 1 ? HIGH : LOW);
  digitalWrite(digitalLight3Pin, pgm_read_byte(&LIGHT_MATRIX[currentLightMode][2]) == 1 ? HIGH : LOW);
}

void LightsController::setLedBirigthness(uint8_t newLedBrightness) {
  ledBrightness = newLedBrightness;
  setLightsPinsByCurrentMode();
}

void LightsController::setLightsMode(uint8_t mode) {
  currentLightMode = mode > MODE_MAX ? MODE_MAX : mode;
  setLightsPinsByCurrentMode();
}

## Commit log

2024-01-28 Button press resolving, button reactions, programming methods - calibrate and adjust.
2024-01-28 Added LightsController which constrolls which leds will be turned on or off and at which brightness lkevel.
2024-01-29 Bug fixing in led setup led output settings.
    Changes in pins configuration to leave as much as possible of PWM pins.
    [AppConstants.h, LedSetup.cpp, LightsController.cpp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]
2024-01-30 Added code for reading motor polarity and revs.
    Implemented potentiometer simulator of opto-isolators and fake driver for them.
2024-01-30 Bug fix, restore lights mode after signal of receiver is restored.
    [LedControlBlinker.cpp, MainApp.cpp, PWMButton.cpp]
2024-07-16 working on schematic
    [T815-DKR-86-Schema.kicad_pcb, T815-DKR-86-Schema.kicad_sch]
2024-07-17 Relevant version using mosfets.
    [T815-DKR-86-Schema.kicad_sch]
2024-07-17 cosmetic changes in layout.
    [T815-DKR-86-Schema.kicad_sch]
2024-07-21 better threshold for reverse detection
    [RCThrottleHandler.cpp]
2024-07-23 Removing dependency on information that motor is spinning forward. Thes light module does not need that information.
    [T815-DKR-86-Schema.kicad_sch]
2024-07-24 revised version. corrected transistors connections.
    [T815-DKR-86-Schema.kicad_sch]
2024-07-24 Schema revision 2
    [T815-DKR-86-Schema.kicad_sch]
2024-07-27 get ready for more clever button class
    [T815-DKR-86-Schema.kicad_sch]
2024-07-27 lettle refactor of rc pwm button
2024-07-27 new button base class and reimplemented rc pwm button
2024-07-27 added new digital pull up button class and attached one instance on A0 as temporary demo
2024-07-31 new version of schema using new schematic layouts to be able make good pcb layout. Typicaly led arrays are realies as connector with common ground, not a many plus and minus wires.
    [T815-DKR-86-Optimalized.kicad_pcb, T815-DKR-86-Optimalized.kicad_sch, T815-DKR-86-Schema.kicad_sch]
2024-07-31 Better calibration.
2024-08-07 functional calibration and rc channel signal detection.
2024-08-07 Refactored calibration and the way of store/restore eprom calibration data
2024-08-07 Buttons refactored for better and more logical usage.
2024-08-07 Bug fix at PwmRcButton + enabled whole application.
    [MainApp.cpp]
2024-08-07 Throttle handler refactor, it uses rc channel instane now.
2024-08-07 led animators refactor
2024-08-07 bug fix reading eprom
    [AppConstants.h, CalibrationManager.cpp, LedBlinker.cpp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]
2024-08-07 removed debug prints in initialization method.
2024-08-08 led blinker allows setup PWM led brightness for each step of animation. So fading effects are now supported.
2024-08-13 schema update - rearanged pins.
    [T815-DKR-86-Optimalized.kicad_pcb, T815-DKR-86-Optimalized.kicad_sch]
2024-08-20 schema update - pcb more optima use of arduino pins
    [T815-DKR-86-Optimalized.kicad_pcb, T815-DKR-86-Optimalized.kicad_sch]
2024-09-01 Changed pins numbers usage to respond with physical HW layout.
    [T815-DKR-86-Optimalized.kicad_sch]
